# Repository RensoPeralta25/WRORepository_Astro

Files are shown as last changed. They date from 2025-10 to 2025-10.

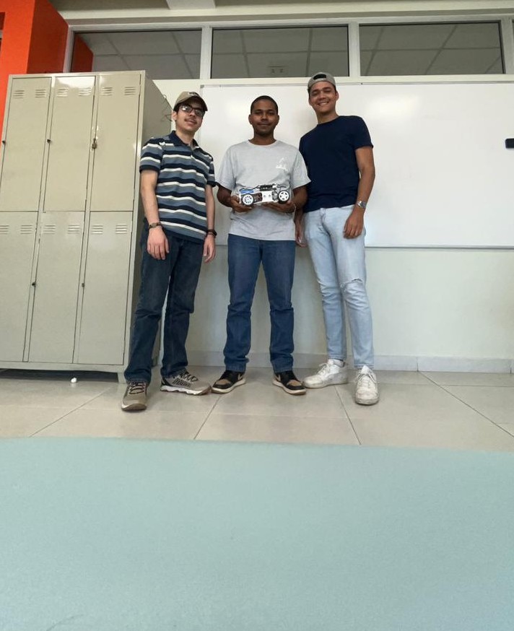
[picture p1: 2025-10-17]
t-photos/team photo.jpg

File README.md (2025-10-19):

# WRO Repository TEAM Astro
## Team Information

<p align="center">
  
</p>

📜 Documenter: Renso Isael Peralta Ureña (Right)

🧑‍🔧 Programmer: José Miguel Comprés Arias (Left)

🧑‍🔧 Mechanic: Yoel Samuel Castillo Castillo (Front)

team photo

PUCMM, Dominican Republic 

## Content Organization

This repository contains the complete documentation and resources for our autonomous vehicle designed for the WRO 2025 Future Engineers category from ASTRO team.

## Table of Contents

- [Introduction](#introduction)
- [Project Overview](#project-overview)
- [Models](#models)
  - [Main Components](#main-components)
  - [First Prototype Design](#first-prototype-design)
  - [Second Prototype Design](#second-prototype-design)
- [Sources (src)](#sources-src)
  - [Arduino Code](#what-does-this-code-do)
  - [Button Launcher](#code-bottompy)
  - [Autonomous Navigation](#code-openchallengepy)
- [Schemes](#schemes)
- [Vehicle Photos](#v-photos)

### Repository Structure

* **`t-photos`** - Contains the photo of the team:
  * Official team photo with all members

* **`v-photos`** - Contains 6 photos of the vehicle showcasing:
  * Front view
  * Back view
  * Left side view
  * Right side view
  * Top view
  * Bottom view

* **`videos`** - Contains `video.md` file with links to driving demonstration videos including:
  * Tests carried out

* **`schemes`** - Contains electromechanical schematic diagrams (JPEG/PNG/PDF form``at) illustrating:
  * IMU (MPU-9250) I2C Connection Diagram
  * Complete System Wiring Diagram
  * Dual Ultrasonic Sensors Configuration
  * Power Distribution

* **`src`** - Contains the control software source code:
  * Open Challenge 
  * projecthub.arduino.cc
  * bottom.py

* **`models`** - Contains 3D models and design files:
  * Files for 3D-printed parts.
  * First prototype design files.
  * Second prototype design files (optimized version).

## Introduction
This project presents our autonomous vehicle designed for the 2025 World Robot Olympiad (WRO) competition in the Future Engineers category. The robot is fully autonomous, capable of navigating a closed course, detecting and avoiding objects.

AUTONOMOUS NAVIGATION ROBOT

## Project Overview
This repository contains all the technical documentation, code, and design files for our autonomous navigation robot developed for the WRO Future Engineers. Our project focuses on creating a practical and efficient self-driving vehicle capable of navigating complex environments using sensor fusion and intelligent decision-making algorithms.

## Models

### Main components
- **Main Controller**: Raspberry Pi 5 (high-level processing)


[Link to buy the raspberry pi 5](https://www.amazon.com/-/es/SC1112-Raspberry-Pi-5-8GB/dp/B0CK2FCG1K/ref=sr_1_3_mod_primary_new?sr=8-3)

- **Real-time Controller**: Arduino UNO R3


[Link to buy the arduino UNO R3](https://www.amazon.com/-/es/Arduino-Uno-R3-Microcontrolador-A000066/dp/B008GRTSV6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)

- **Interface Board**: Robot Hat v4


[Link to buy Robot Hat v4](https://www.amazon.com/-/es/SunFounder-expansi%C3%B3n-Raspberry-conductores-recargable/dp/B0CKTD7QJB)

- **Sensors**:
  - 2x Ultrasonic sensors HCSR04 (Bilateral coverage)
  
  

  [Link to buy ultrasonic sensors HCSR04](https://www.amazon.com/-/es/DIYables-ultras%C3%B3nico-HC-SR04-Arduino-Raspberry/dp/B0BDFLPZ2R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)

  - 1x Color sensor TCS 3200 (line detection)
  
  

  [Link to buy Color Sensor TCS 3200](https://www.amazon.com/-/es/Teyleten-TCS3200-TCS230-reconocimiento-Arduino/dp/B08HH8QYF8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)

  - 1x IMU MPU-9250 (orientation)
  
  

  [Link to buy IMU MPU-9250](https://www.amazon.com/-/es/giroscopio-magn%C3%A9tico-aceleraci%C3%B3n-acelerador-magnet%C3%B3metro/dp/B01I1J0Z7Y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)
 
  - 1x Raspberry Pi Camera (computer vision)
  
  

  [Link to buy Raspberry Pi Camera](https://www.amazon.com/-/es/Arducam-peque%C3%B1o-megapixeles-pixeles-Raspberry/dp/B012V1HEP4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)

- **Motors**: TT Motor x1
  
  

  [Link to buy TT Motor](https://www.amazon.com/-/es/Diann-unids-Motor-cambios-200RPM/dp/B0BR7S2TRY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)

- **Power Source**: Battery
  
  

  [Link to buy Battery](https://www.indiamart.com/proddetail/5v-li-ion-battery-22444168691.html)

## First Prototype Design



Our initial chassis design was conceived with a compact, enclosed structure that prioritized sensor integration and component protection. The first prototype incorporated the following design elements:

*Sensor Layout*:
The chassis featured mounting positions for four ultrasonic sensors strategically distributed to provide comprehensive obstacle detection coverage around the vehicle's perimeter.

*Camera Integration*:
A dedicated frontal mounting space was designed to house the Raspberry Pi Camera module, positioned to provide an optimal field of view for computer vision and object detection tasks.

*Internal Electronics Compartment*:
The original design included an enclosed internal cavity intended to house all electronic components, including the Raspberry Pi 5, Robot Hat v4, Arduino, sensors, and wiring. This approach aimed to protect the electronics from external interference and provide a clean, organized appearance.

*Motor Placement*:
A designated space was allocated for the DC motor; however, the initial design lacked detailed consideration for motor mounting mechanics, power transmission, and drivetrain integration.

*Critical Design Oversight*:
During the physical assembly phase, we encountered a significant spatial constraint that was not apparent in the CAD model. The combined height of the Raspberry Pi 5 board and the Robot Hat v4 interface board exceeded the available vertical clearance within the internal compartment. We had not physically measured these stacked components during the design phase, assuming the CAD dimensions would accommodate them.

*Consequence*: The electronics could not fit inside the chassis as originally planned.

*Immediate Solution*: We repositioned the Raspberry Pi 5 and Robot Hat v4 assembly on top of the chassis structure, securing them with standoffs and mounting brackets. While this modification solved the spatial issue and improved heat dissipation and accessibility, it exposed the electronics to potential impacts and increased the vehicle's center of gravity.

Motor Integration Challenge:
Similarly, the motor mounting system was insufficiently detailed in the first prototype. The lack of proper motor brackets, shaft alignment considerations, and drivetrain coupling mechanisms became evident during assembly.

Resolution: This oversight necessitated a complete chassis redesign to properly integrate the motor system, optimize weight distribution, and ensure reliable power transmission to the wheels.

This experience highlighted the critical importance of:

*Physical measurement and test-fitting of components before finalizing CAD designs
Accounting for tolerance stack-up and assembly clearances
Detailed planning of mechanical subsystems (motor mounts, drivetrain, wiring routes)
Iterative prototyping to validate design assumptions*

These challenges directly informed the development of our second prototype, which addressed all identified spatial and mechanical integration issues.

## Second Prototype Design

After evaluating the limitations of our first prototype, we decided to completely redesign the chassis to optimize sensor positioning and improve overall functionality. Building on lessons learned, we planned to incorporate five ultrasonic sensors for enhanced environmental awareness.

Ultrasonic Sensor Holder Design

chasis largo

We designed a dedicated ultrasonic sensor holder to accommodate the five sensors we intended to use: two positioned at the front for forward obstacle detection, one at the rear for reverse awareness, and two mounted mid-chassis for lateral coverage. While this configuration seemed optimal in theory, practical testing revealed a critical flaw—the two front-mounted sensors created physical interference with the front wheel assembly during steering maneuvers, necessitating their removal from the chassis.



Front Wheel Support Structure

soporte rueda

Unlike the first design, the second prototype featured an improved front wheel support system. This component served a dual purpose: securely mounting the wheel assembly while providing a stable connection point to the vehicle's outer cover. The redesigned support improved structural rigidity and simplified the assembly process.

segundo soporte ruedas

Second Prototype Assembly Views



🔧 Challenges and Solutions During Final Design

During the development and assembly of our autonomous vehicle, we encountered several technical challenges that required creative solutions and design modifications. These challenges taught us valuable lessons about iterative design and practical engineering problem-solving.



Dimensional Compliance: Reducing Vehicle Length

Critical Constraint: Competition regulations required vehicles to not exceed specific dimensional limits. Our second prototype measured 11.8 inches in length, exceeding the maximum allowed dimension by one full inch.



Problem: The chassis design, while functionally sound, was too long to comply with competition rules. The extended length was primarily due to:

The frontal sensor mounting structure extending beyond necessary limits
The battery holder positioned too far forward
Overall chassis design that prioritized component spacing over compactness

Solution - Comprehensive Chassis Modification:
We implemented a series of strategic modifications to reduce the vehicle's footprint:

Front Section Reduction: We cut and removed approximately one inch from the front portion of the chassis, eliminating excess material while maintaining structural integrity for the camera mount and essential frontal components.

Color Sensor Relocation: Instead of mounting the TCS 3200 color sensor externally on the front surface, we created a custom opening on the underside (bottom) of the chassis. This modification allowed us to recess the sensor into the chassis body, positioning it closer to the ground for optimal line detection while recovering valuable frontal space.

Battery Holder Repositioning: We recessed the battery mounting bracket deeper into the chassis cavity, moving it further back from the front edge. This change not only reduced overall length but also improved weight distribution by centering the battery mass.



Ultrasonic Sensor Reduction: To accommodate the shortened chassis and address other constraints (detailed below), we removed three ultrasonic sensors from the design, further simplifying the frontal structure.

Result: These combined modifications successfully reduced the vehicle length from 11.8 inches to 10.8 inches, achieving full compliance with competition regulations while maintaining all essential functionality.

Arduino Pin Limitations and Sensor Reduction

Problem: Our initial plan to use five ultrasonic sensors, combined with the color sensor, IMU, camera interface, servo motor, and DC motor driver, exceeded the available GPIO pins on the Arduino UNO R3. Each ultrasonic sensor requires two digital pins (trigger and echo), meaning five sensors would consume 10 pins alone, leaving insufficient pins for other critical components.

Solution: We strategically reduced the ultrasonic sensor count from five to two, retaining only the most essential sensors for navigation:

One front-facing sensor for primary obstacle detection
One side-mounted sensor for wall-following and lateral awareness



This reduction freed up six digital pins (3 sensors × 2 pins each), allowing all remaining components to be properly connected without requiring a larger microcontroller.
Ultrasonic Sensor Interface Selection: Raspberry Pi vs. Arduino
Problem: During initial testing, we attempted to interface the ultrasonic sensors directly with the Raspberry Pi 5 GPIO pins. However, we encountered persistent issues with unreliable distance readings and inconsistent sensor response times. The problem stemmed from the Raspberry Pi's non-real-time operating system (Linux), which cannot guarantee precise microsecond-level timing required for accurate ultrasonic echo pulse measurement.
Solution: We decided to connect the ultrasonic sensors to the Arduino UNO R3 instead of the Raspberry Pi. The Arduino's real-time microcontroller architecture provides deterministic timing, ensuring accurate pulse duration measurements. The Arduino reads the sensor data and transmits processed distance values to the Raspberry Pi via serial communication (UART) through the Robot Hat v4 interface.
Technical Justification:

Arduino UNO R3: Real-time operation with precise microsecond timing for reliable ultrasonic measurements
Raspberry Pi 5: Handles higher-level processing (computer vision, navigation logic, decision-making) without timing-critical sensor interfacing

This division of responsibilities between the two processors optimized system reliability and performance.
Color Sensor Integration
One of the first challenges we faced was fitting the color sensor into its designated mounting space. The original CAD design did not account for the actual physical dimensions and connector orientation of the TCS 3200 color sensor module.
Problem: The color sensor module, including its I2C connector pins, exceeded the allocated space in the front sensor mount structure. The rigid PCB design prevented us from repositioning it without structural modifications.
Solution: We used a soldering iron to carefully create a custom opening in the bottom of the plastic chassis. This allowed us to recess the sensor body while keeping the optical window at the optimal height and angle for line detection. The modification maintained the sensor's downward-facing orientation (approximately 30-45° angle) necessary for accurate color detection of the track surface while minimizing ambient light interference.
Result: The color sensor was successfully integrated and provided reliable line detection throughout testing while contributing to the overall length reduction of the chassis.
Rear Wheel Support Structure Failure
Problem: The 3D-printed rear wheel support arms, designed to hold rubber tires in place, experienced structural failure during initial testing. The stress concentration points where the tires connected to the motor shafts caused the plastic supports to crack and eventually break. This was likely due to:

Insufficient wall thickness in the 3D-printed part
Vibrations from the DC motors during operation
Lateral forces during turning maneuvers

Solution: Unable to quickly redesign and reprint the support structure, we implemented an emergency repair using a soldering iron technique:

We carefully heated the soldering iron to a temperature suitable for melting PLA/ABS plastic
We repositioned the broken rubber tire holders against the motor mounting arms
We used the soldering iron tip to "weld" the plastic pieces together, creating a reinforced joint
We added additional plastic material where needed to strengthen critical stress points

Result: This field repair successfully restored structural integrity and proved durable enough for the remainder of our testing and competition preparation. However, this experience highlighted the importance of stress testing 3D-printed components and designing with appropriate safety margins for dynamic loads.
Microcontroller Selection Optimization
Our electronic architecture underwent a significant simplification during the final assembly phase.
Original Plan: Arduino Mega 2560

Reason for selection: The Mega provides 54 digital I/O pins and 16 analog inputs, which we initially believed necessary to accommodate multiple ultrasonic sensors, the color sensor (I2C), the IMU (I2C), servo motors (PWM pins), and the DC motor driver.

Modified Implementation: Arduino UNO R3

Reason for change: After reducing the ultrasonic sensor count to two, the total pin requirement decreased significantly:

2 ultrasonic sensors: 4 digital pins (2 trigger + 2 echo)
Color sensor: I2C bus (SDA/SCL) - 2 pins
IMU: I2C bus (shared) - 0 additional pins
Servo motor (steering): 1 PWM pin
DC motor driver: 2-4 digital pins
Total: approximately 9-11 pins

The Arduino UNO R3 provides 14 digital I/O pins and 6 analog inputs, which is more than sufficient for our reduced configuration. This change offered several advantages:

Reduced physical footprint: The Uno is smaller and lighter than the Mega
Improved space utilization: Easier to fit within the compact chassis
Cost optimization: Lower component cost without sacrificing functionality
Simplified wiring: Fewer unused pins reduced wiring complexity
Real-time sensor reliability: Better ultrasonic sensor performance compared to Raspberry Pi GPIO

Power Distribution Solution
Managing multiple 5V power connections for sensors and modules with limited power pins on the Arduino.
Solution: We implemented a breadboard-based power distribution system:

Positive rail (5V): Connected to Arduino's 5V output pin
Ground rail (0V/GND): Connected to Arduino's GND pin
Connected devices: All sensors requiring 5V power (ultrasonic sensors, color sensor) were connected to the breadboard rails

Advantages:

Organized and accessible power distribution
Easy troubleshooting and component replacement
Reduced stress on Arduino's voltage regulator by distributing current load
Clean cable management

## Sources (src)

File: projecthub.arduino.cc

## What does this code do?

This code controls an Arduino robot that can:
- **Detect distances** to the left and right using ultrasonic sensors
- **Identify colors** using a TCS3200/230 sensor
- **Rotate** using a servo motor
- **Communicate** with a computer via serial port

## Hardware Connections

### Left Ultrasonic Sensor:
- `TRIG` → Pin 7
- `ECHO` → Pin 6
- `VCC` → 5V
- `GND` → GND

### Right Ultrasonic Sensor:
- `TRIG` → Pin 5
- `ECHO` → Pin 4
- `VCC` → 5V
- `GND` → GND

### TCS3200 Color Sensor:
- `S0` → Pin 8
- `S1` → Pin 9
- `S2` → Pin 10
- `S3` → Pin 11
- `OUT` → Pin 12
- `VCC` → 5V
- `GND` → GND

### Servo Motor:
- Signal Wire → Pin 3
- Red Wire → 5V
- Brown/Black Wire → GND

## 📚 Required Libraries

Before uploading the code, install these Libraries:

```cpp
#include <Servo.h> // To control the servo
#include <SR04.h> // For ultrasonic sensors
```

**Installation:** In the Arduino IDE, go to `Tools > Manage Libraries` and search for these libraries.

## Step-by-Step Code Explanation

### 1. Pin Definitions

```cpp
// ULTRASONIC PINS
#define TRIG_PIN_L 7 // Left sensor trigger pin
#define ECHO_PIN_L 6 // Left sensor echo pin
#define TRIG_PIN_R 5 // Right sensor trigger pin
#define ECHO_PIN_R 4 // Right sensor echo pin

// COLOR SENSOR PINS
#define s0 8 // Frequency setting
#define s1 9 // Frequency setting
#define s2 10 // Color filter selection
#define s3 11 // Color filter selection
#define out 12 // Frequency output

// SERVO PIN
#define SERVO_PIN 3 // Servo control pin
```

### 2. Variables globals

```cpp
int data = 0; // Stores the color frequency
int degs; // Degrees for the servo
long distance_usl; // Left sensor distance
long distance_usr; // Right sensor distance
```

### 3. Object Creation

```cpp
SR04 ul = SR04(ECHO_PIN_L, TRIG_PIN_L); // Left ultrasonic sensor
SR04 ur = SR04(ECHO_PIN_R, TRIG_PIN_R); // Right ultrasonic sensor
Servo servo; // Servo object
```

### 4. Initial Setup

```cpp
void setup() {
Serial.begin(9600); // Start serial communication

// Configure color sensor pins
pinMode(s0, OUTPUT);
pinMode(s1, OUTPUT);
pinMode(s2,OUTPUT);
pinMode(s3,OUTPUT);
pinMode(out,INPUT);

// Sets frequency to 100% (maximum precision)
digitalWrite(s0,HIGH);
digitalWrite(s1,HIGH);

// Starts servo in center position (70°)
servo.attach(SERVO_PIN);
servo.write(70);

delay(2000); // Waits 2 seconds to stabilize
}
```

### 5. Main Loop

The code performs the following operations continuously:

#### a) Servo control via serial
```cpp
if (stringComplete) {
inputString.trim(); // Clears spaces
degs = inputString.toInt(); // Converts text to numbers
servo.write(degs); // Move the servo
inputString = "";
stringComplete = false;
}
```

**Servo limits:**
- Right: 30°
- Left: 130°
- Center: ~70-80°

#### b) Reading ultrasonic sensors
```cpp
distance_usl = ul.Distance(); // Left distance in cm
distance_usr = ur.Distance(); // Right distance in cm
```

#### c) Reading the color sensor

The sensor detects the RGB components of the reflected light:

```cpp
// Detect RED
digitalWrite(s2, LOW);
digitalWrite(s3, LOW);
int r = pulseIn(out, LOW);

// Detect GREEN
digitalWrite(s2, LOW);
digitalWrite(s3, HIGH);
int g = pulseIn(out, LOW);

// Detect BLUE
digitalWrite(s2, HIGH);
digitalWrite(s3, HIGH);
int b = pulseIn(out, LOW);
```

**How does it work?**
- S2/S3 combinations select which color to detect
- `pulseIn` measures the pulse time (shorter time = greater color intensity)

#### d) Sending data
```cpp
Serial.println(String(distance_usl) + "|" + String(distance_usr) + "|" +
String(r) + "|" + String(g) + "|" + String(b));
```

Output format: `distance_left|distance_right|red|green|blue`

### 6. Receiving serial commands

```cpp
void serialEvent() {
while (Serial.available()) {
char inChar = (char)Serial.read();
if (inChar == '\n') {
stringComplete = true; // Mark the command complete
} else {
inputString += inChar; // Construct the command
}
}
}
```

This function is executed automatically when data arrives via serial.

## Code: bottom.py

This Python script creates a simple button-controlled system that:

Monitors a button for press events
Controls an LED to indicate button state
Launches another Python script when the button is pressed
Prevents accidental multiple triggers with debouncing

This is perfect for robots or projects where you need a physical button to start a specific program or routine.
Required Libraries
This project uses the robot_hat library, which is typically included with SunFounder robot kits:
bash# If not already installed:
pip3 install robot-hat
```

## 🔌 Hardware Connections

### Button Connection:
- One side → GPIO25 (labeled as "SW" on some boards)
- Other side → GND
- Internal pull-up resistor enabled (no external resistor needed)

### LED Connection:
- LED anode (long leg) → GPIO26 through 220Ω resistor
- LED cathode (short leg) → GND

```
              +         -
Code Explanation - Line by Line
1. Import Required Libraries
pythonfrom robot_hat import Pin
import time
import os

robot_hat: Provides easy GPIO control for Raspberry Pi
time: For delays and preventing button bounce
os: To execute system commands (run other scripts)

2. Hardware Setup
pythonbutton = Pin("SW", Pin.IN, Pin.PULL_UP)   # Button USR (GPIO25)
led = Pin(26, Pin.OUT)                    # LED (GPIO26)
Button Configuration:

"SW": Special label for GPIO25 (user switch)
Pin.IN: Sets pin as input
Pin.PULL_UP: Enables internal pull-up resistor

Button reads HIGH (1) when not pressed
Button reads LOW (0) when pressed

LED Configuration:

26: GPIO pin number
Pin.OUT: Sets pin as output

3. Define Script Path
python# Path to the file you want to execute
script_path = "/home/admin/Documents/pruebaAbierta1.py"
This is the full path to the Python script that will run when the button is pressed.
Important: Update this path to match your script location!
4. Main Control Loop
pythonwhile True:
    if button.value() == 1:  # Pressed
        led.on()
        os.system(f"python3 {script_path}")  # Execute the other script
        time.sleep(0.5)  # Avoid repetition due to bounce
    else:
        led.off()
    time.sleep(0.1)
Loop Behavior:

Button Check: button.value() returns:

1 when button is pressed (connected to ground)
0 when button is not pressed (pulled high)

When Button is Pressed:

LED turns ON
External script executes using os.system()
0.5 second delay prevents multiple triggers (debouncing)

When Button is Released:

LED turns OFF

Loop Delay:

0.1 second delay reduces CPU usage
Provides responsive button checking (~10 checks per second)

How to Use This Code
Step 1: Setup Your Hardware

Connect the button to GPIO25 and GND
Connect the LED to GPIO26 (with resistor) and GND
Power up your Raspberry Pi

Step 2: Prepare Your Scripts

Save this launcher script (e.g., as button_launcher.py)
Create or locate the script you want to launch
Update the script_path variable with the correct path

Step 3: Run the Launcher
bashpython3 button_launcher.py
Step 4: Test the System

Press the button → LED lights up and your script runs
Release the button → LED turns off
The launcher continues running, ready for the next press

Use Cases
This button launcher is perfect for:

Robot startup sequences - Press to begin autonomous navigation
Data collection triggers - Start sensor logging on demand
Mode switching - Toggle between different robot behaviors
Emergency stops - Launch shutdown or safe mode scripts
Demo activation - Start presentation routines

## Code: openChallenge.py

This Python script creates an autonomous robot that:
- **Navigates using ultrasonic sensors** (left and right distance detection)
- **Adjusts steering automatically** based on sensor readings
- **Captures video feed** from a Raspberry Pi camera
- **Detects colored lines** for navigation markers (using RGB sensor)
- **Communicates with Arduino** via serial for sensor data and servo control

The robot uses a wall-following algorithm to navigate corridors or paths while avoiding obstacles.

### Software Requirements:
```bash
# Install required Python packages
pip3 install pyserial
pip3 install opencv-python
pip3 install picamera2
# Astro library (specific to robot kit)
```

## System Architecture

```

┌─────────────┐     Serial      ┌─────────────┐
│  Raspberry  │◄──────────────► │   Arduino   │
│     Pi      │    /dev/ttyACM0 │             │
└──────┬──────┘                 └──────┬──────┘
       │                                │
   ┌───┴───┐                     ┌─────┴─────┐
   │  HAT  │                     │  Sensors  │
   └───┬───┘                     │  & Servo  │
       │                         └───────────┘
   ┌───┴───┐
   │ Motor │
   └───────┘

```

## Key Parameters and Constants

```python
SERIAL_PORT = "/dev/ttyACM0"  # Arduino serial connection
BAUD_RATE   = 9600            # Serial communication speed

DISCR_DIST  = 3               # Distance threshold (unused in current version)
REDIR_ANGLE = 40              # Redirection angle for turns
CENTER = 70                   # Servo center position (degrees)
MAX_ANGLE = 40                # Maximum steering angle from center
```

### Servo Limits:
- **Minimum angle**: CENTER - MAX_ANGLE = 30°
- **Maximum angle**: CENTER + MAX_ANGLE = 110°
- **Center/Straight**: 70°

##  Code Explanation - Section by Section

### 1. Imports and Setup

```python
from astro import Astro      # Robot control library
import serial                # Arduino communication
import time                  # Delays and timing
import cv2                   # Image processing
from picamera2 import Picamera2  # Camera interface
```

### 2. Camera Initialization

```python
picam2 = Picamera2()

# Configure camera resolution
config = picam2.create_preview_configuration({"size": (640, 480)})
picam2.configure(config)

picam2.start()
time.sleep(0.2)  # Allow camera to stabilize
```

The camera runs at 640x480 resolution for a balance between quality and performance.

### 3. Helper Functions

#### Constrain Function
```python
def constrain(x, mn, mx):
    return max(mn, min(mx, x))
```
Limits a value between minimum and maximum bounds (used for servo angles).

#### Serial Communication
```python
def sensor_comm(command):
    ser.write((command + "\n").encode('utf-8'))
```
Sends commands to Arduino (primarily servo angle values).

### 4. Data Reading Functions

The code includes three versions of the data reading function, with `leer_datos3` being the most robust:

```python
def leer_datos3(timeout_seconds=1.0):
    start = time.time()
    
    while True:
        linea = ser.readline().decode(errors="ignore").strip()
        
        # Timeout check
        if not linea:
            if time.time() - start > timeout_seconds:
                raise ValueError("Timeout: no data received")
            continue
        
        # Format validation
        if "|" not in linea:
            if time.time() - start > timeout_seconds:
                raise ValueError(f"Malformed line: {linea!r}")
            continue
        
        # Parse data
        partes = linea.split("|")
        
        # Pad missing values with zeros
        while len(partes) < 5:
            partes.append("0")
        
        # Extract values
        usl_str, usr_str, r_str, g_str, b_str = partes[:5]
        
        try:
            usl = float(usl_str)  # Left ultrasonic
            usr = float(usr_str)  # Right ultrasonic
            r = float(r_str)      # Red component
            g = float(g_str)      # Green component
            b = float(b_str)      # Blue component
            return usl, usr, r, g, b
        except ValueError:
            if time.time() - start > timeout_seconds:
                raise
            continue
```

**Data Format**: `left_distance|right_distance|red|green|blue`

### 5. Main Navigation Loop

```python
# Initialize robot
bot = Astro()
line_count = 0

bot.stop()
time.sleep(5)  # Wait before starting

# Get initial sensor sum
left_dist, right_dist, r, g, b = leer_datos3()
Sum_Initial = left_dist + right_dist

while True:
    # Move forward
    bot.forward(90)  # Speed: 90
    
    # Read sensors
    left_dist, right_dist, r, g, b = leer_datos3()
    
    # Capture and display camera image
    img = picam2.capture_array()
    img_bgr = cv2.cvtColor(img, cv2.COLOR_RGB2BGR)
    cv2.imshow("CSI Camera (Picamera2 -> OpenCV)", img_bgr)
    
    # Calculate current sum
    Sum_Temp = left_dist + right_dist
    
    # Navigation algorithm
    if(Sum_Temp - 10 < Sum_Initial):
        # Walls closing in - adjust based on difference
        angle = CENTER + float(left_dist - right_dist) * (float(MAX_ANGLE) / 30)
        sensor_comm(str(constrain(angle, CENTER - MAX_ANGLE, CENTER + MAX_ANGLE)))
        
    elif(Sum_Temp - 10 > Sum_Initial):
        # Walls opening up - adjust based on sum
        angle = CENTER + float(left_dist + right_dist) * (float(MAX_ANGLE) / 30)
        sensor_comm(str(constrain(angle, CENTER - MAX_ANGLE, CENTER + MAX_ANGLE)))
        
    else:
        # Maintain center
        sensor_comm("70")
```

### 6. Navigation Algorithm Explained

The robot uses a **corridor-following algorithm**:

1. **Initial Calibration**: Records the sum of left and right distances at start
2. **Continuous Monitoring**: Compares current sum with initial sum
3. **Steering Decisions**:
   - **Walls closing in** (Sum_Temp < Sum_Initial - 10):
     - Steers based on the difference between sensors
     - Moves away from the closer wall
   - **Walls opening up** (Sum_Temp > Sum_Initial + 10):
     - Uses the sum of distances for steering
     - Helps navigate open areas
   - **Normal corridor**: Maintains center position

### 7. Alternative Navigation Code (Commented Out)

The code includes an alternative navigation method:

```python
# Smooth out noisy readings
real_l = left_dist
if (abs(last_l - left_dist) > 10):
    real_l = last_l  # Use last value if change too large

# Different steering sensitivity based on distance difference
if abs(left_dist - right_dist < 40):
    # Normal steering
    angle = CENTER + float(real_l - real_r) * (float(MAX_ANGLE) / 20)
else:
    # More aggressive steering for larger differences
    angle = CENTER + float(real_l - real_r) * (float(50) / 20)

# Line detection for counting laps/sections
if min(r, min(g, b)) == r and r < min(g, b):
    line_count += 1  # Red line detected
```

### 8. Error Handling

```python
try:
    # Main code
except serial.SerialException as e:
    print(f"ERROR opening port: {e}")
except KeyboardInterrupt:
    print("\nReading stopped by user.")
finally:
    # Cleanup
    if 'ser' in locals() and ser.is_open:
        ser.close()
    picam2.stop()
    cv2.destroyAllWindows()
```

## How to Use This Code

### Step 1: Hardware Setup
1. Connect Arduino to Raspberry Pi via USB
2. Upload the Arduino sensor code (from previous tutorial)
3. Mount ultrasonic sensors pointing left and right
4. Connect camera to CSI port
5. Ensure robot wheels and servo are properly connected

### Step 2: Software Configuration
1. Find Arduino port:
   ```bash
   ls /dev/tty*  # Look for /dev/ttyACM0 or /dev/ttyUSB0
   ```
2. Update `SERIAL_PORT` if different
3. Install required libraries

### Step 3: Run the Robot
```bash
python3 autonomous_robot.py
```

### Step 4: Monitor Operation
- Camera feed window shows real-time view
- Terminal displays sensor readings
- Press `Ctrl+C` to stop safely

## Understanding the Output

### Terminal Output:
```
RAW: 15|20|150|200|180
Distancia izquierda: 15.0
Distancia derecha: 20.0
Sumatoria Inicial: 35.0
Sumatoria: 35.0
```

- **RAW**: Raw serial data from Arduino
- **Distance values**: In centimeters
- **Sum values**: Used for navigation decisions

## 🔧 Tuning and Optimization

### 1. Steering Sensitivity
```python
# Current formula: MAX_ANGLE / 30
# Increase divisor for less sensitive steering
angle = CENTER + float(left_dist - right_dist) * (float(MAX_ANGLE) / 30)

# More sensitive (faster reactions)
angle = CENTER + float(left_dist - right_dist) * (float(MAX_ANGLE) / 20)

# Less sensitive (smoother movement)
angle = CENTER + float(left_dist - right_dist) * (float(MAX_ANGLE) / 40)
```

### 2. Speed Control
```python
# Current: constant speed
bot.forward(90)

# Dynamic speed based on obstacles
if min(left_dist, right_dist) < 15:
    bot.forward(60)  # Slow down near walls
else:
    bot.forward(90)  # Normal speed
```

### 3. Wall Detection Threshold
```python
# Current: 10cm buffer
if(Sum_Temp - 10 < Sum_Initial):

# More sensitive to changes
if(Sum_Temp - 5 < Sum_Initial):

# Less sensitive (for wider corridors)
if(Sum_Temp - 15 < Sum_Initial):
```

## Advanced Features

### Add Obstacle Avoidance
```python
# Emergency stop for close obstacles
if min(left_dist, right_dist) < 5:
    bot.stop()
    time.sleep(0.5)
    bot.backward(70)
    time.sleep(1)
```

### Implement PID Control
```python
# Simple proportional control upgrade
error = left_dist - right_dist
integral += error * dt
derivative = (error - last_error) / dt

# PID formula
steering = Kp * error + Ki * integral + Kd * derivative
angle = CENTER + constrain(steering, -MAX_ANGLE, MAX_ANGLE)
```

### Add Path Memory
```python
path_history = []
position_estimate = {"x": 0, "y": 0, "heading": 0}

# Log movements
path_history.append({
    "time": time.time(),
    "left": left_dist,
    "right": right_dist,
    "steering": angle
})
```

## Troubleshooting

### Serial Communication Issues:
- **"No data received"**: Check Arduino is sending data
- **"Malformed line"**: Verify Arduino data format
- **Permission denied**: Add user to dialout group
  ```bash
  sudo usermod -a -G dialout $USER
  ```

### Camera Issues:
- **Black screen**: Enable camera in `raspi-config`
- **Import error**: Install picamera2 dependencies
- **Slow performance**: Reduce resolution

### Navigation Problems:
- **Hitting walls**: Increase MAX_ANGLE or sensitivity
- **Zigzag movement**: Decrease sensitivity or add smoothing
- **Not turning**: Check servo connections and limits

## Performance Optimization

### 1. Reduce Serial Latency
```python
# Add to setup
ser.set_low_latency_mode(True)
```

### 2. Optimize Image Processing
```python
# Skip frames for display
frame_count = 0
if frame_count % 5 == 0:  # Show every 5th frame
    cv2.imshow("Camera", img_bgr)
frame_count += 1
```

### 3. Multi-threading
```python
import threading

def camera_thread():
    while running:
        img = picam2.capture_array()
        # Process image
        
def sensor_thread():
    while running:
        data = leer_datos3()
        # Process sensors
```
## Schemes

Overview
These schematics show the complete wiring connections for an autonomous robot using Arduino UNO R3 as the main microcontroller, featuring multiple sensors for navigation and environmental awareness.

IMU (MPU-9250) I2C Connection Diagram



Components:

IMU Digital Combo Board 6DOF (MPU-9250)
Arduino UNO (Rev3)

Connection Details:

  Power Connections:

    3.3V (Red wire) → Arduino 3.3V pin
    GND (Green wire) → Arduino GND pin

  I2C Communication:

    SDA (Blue wire) → Arduino A4/SDA pin
    SCL (Green wire) → Arduino A5/SCL pin

Interrupt Pins (Not connected):

INT0 and INT1 pins are available but not utilized

Important Note: Although the IMU (MPU-9250) is physically connected and shown in the schematic, it is currently not being used in the code implementation due to time constraints. The hardware is ready for future integration when needed.

Complete System Wiring Diagram
This diagram shows the I2C connection between Arduino UNO R3 and the IMU module using the same color coding as diagrama 1.



Image 3: Arduino with Color Sensor (TCS3200)



Components:

Arduino UNO R3
TCS3200 Color Sensor Module

Physical Setup:

The color sensor is connected via jumper wires
Power is supplied through the Arduino's 5V and GND pins
Data pins are connected to digital I/O pins for color frequency reading

Dual Ultrasonic Sensors Configuration



Components:

Arduino UNO
2x HC-SR04 Ultrasonic Sensors
Breadboard (for power distribution)

Wiring Configuration:

Upper Ultrasonic Sensor (Left side):

VCC → 5V power rail (Red wire)
Trig → Digital Pin 7
Echo → Digital Pin 6
GND → Ground rail (Black wire)

Lower Ultrasonic Sensor (Right side):

VCC → 5V power rail (Red wire)
Trig → Digital Pin 5
Echo → Digital Pin 4
GND → Ground rail (Black wire)

Power Distribution:

The breadboard is used to distribute 5V and GND from Arduino to both sensors
This eliminates the need for multiple connections to Arduino's limited power pins

Additional Resources
Note: There is an additional file in the schemes folder called "Ultrasonic schematics" that shows the ultrasonic sensor connection diagram in a different format. This provides an alternative view of the same connections for better clarity.
System Integration Summary

Microcontroller: Arduino UNO R3 serves as the main processing unit

Sensors:
2x HC-SR04 Ultrasonic sensors (active and functioning)
1x TCS3200 Color sensor (active and functioning)
1x MPU-9250 IMU (connected but not implemented in software)

### Communication:

I2C bus for IMU (when implemented)
Digital I/O for ultrasonic sensors
Serial communication with Raspberry Pi via USB

### Power Management

All sensors operate at 5V except the IMU which requires 3.3V
Breadboard used for clean power distribution
Arduino provides regulated power to all components

This modular design allows for easy troubleshooting and future expansion of the sensor array.

## v-photos

### Front

front1

### Back

back1

### Bottom

bottom1

### Left
left1

### Right
right1

### Top
top1

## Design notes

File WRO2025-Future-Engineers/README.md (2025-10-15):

# WRO Repository TEAM Astro
## Introduction
This project presents our autonomous vehicle designed for the 2025 World Robot Olympiad (WRO) competition in the Future Engineers category. The robot is fully autonomous, capable of navigating a closed course, detecting and avoiding objects, and parking itself at the end of the course. 

What makes our design unique:

Our vehicle stands out for its redundant and robust sensor architecture: it integrates four strategically positioned ultrasonic sensors that provide full 360° perimeter detection, a color sensor for precise object identification, and an IMU (Inertial Measurement Unit) that allows the robot to maintain orientation and stability in real time.

The brain of the system is a state-of-the-art Raspberry Pi 5 working in conjunction with an Arduino Mega via the Robot Hat v4, creating a dual architecture that separates high-level processing (vision and decision-making) from real-time control (motors and sensors). This hybrid configuration guarantees ultra-fast responses and system stability.

Visually, the robot features a futuristic, technological design in white, reflecting innovation and modernity. The precision servo steering system ensures smooth and accurate maneuvers, while data fusion from multiple sensors enables reliable autonomous navigation even in challenging track conditions.
## ⚙️ Vehicle Design
- Drive system (e.g., differential rear-wheel)
- Motors (type and quantity) and power source (battery type and specs)
- Sensors used (line, distance, vision) and their location
- Brief summary of CAD and physical layout

### 🚀 First Prototype Design



Our first prototype was designed with a minimalist yet strategic approach to sensor integration and mechanical structure. The initial concept called for five ultrasonic sensors strategically distributed around the chassis to provide full 360-degree obstacle detection coverage: a front-facing center sensor for primary detection, two front-facing sensors angled at 45° (left and right) to cover side blind spots, and two side sensors at 90° for wall following and narrow-space detection. Additionally, a color sensor was integrated into a protruding rectangular structure on the front of the robot, specifically designed to position the sensor at an optimal height with a downward tilt angle to allow for accurate detection of the black circuit line, while minimizing ambient light interference thanks to its wraparound design. For advanced navigation and obstacle recognition, a camera was mounted on the top center of the chassis, enabling visual processing to identify and classify obstacles using computer vision algorithms. Finally, an IMU (Inertial Measurement Unit) was positioned on top of the robot, directly above the center of gravity, to provide precise orientation data (yaw, pitch, and roll angles) and stabilization during navigation, crucial for maintaining straight trajectories and executing turns with angular precision. The mechanical structure was complemented by front arms specifically designed for mounting the front wheels, providing an independent steering system that improves maneuverability and allows for precise turning radius adjustments. The rectangular configuration of the front color sensor mount not only fulfills its sensory function but also acts as a structural element that reinforces the front of the chassis and provides protection against minor impacts.

### 🚀 Second Prototype Design

After having thought about this sketch, for reasons of optimizing the position of sensors, we decided to completely change the design of our autonomous robot. As mentioned before, we wanted to have 6 ultrasonics, to help us have more vision. We took this into account for the next version of the design, and also at first we did not think about the location of the engine, this was optimized.





## 🧠 Software Architecture
- Overview of your control strategy
- Code modules (e.g., `line_tracking.py`, `sign_detection.py`)
- Communication or data flow between modules
- Programming language(s) and runtime platform (e.g., Raspberry Pi, Arduino)
## 🔧 Build Instructions
- List of all components used (with part numbers or links if possible)
- Step-by-step physical assembly instructions
- CAD file references or screenshots
## 💾 Code Deployment
- How to set up the environment
- How to install dependencies (requirements.txt)
- How to upload/execute code on your platform
- Any hardware-specific notes or configurations
## 🎥 Test and Evaluation Videos
- Add public links to at least 30-second videos for each required task:
  - Line Following
  - Traffic Sign Detection
  - Obstacle Avoidance
  - Autonomous Parking
- Include a brief description of each video
## 📁 Repository Structure
```text
📂 WRO2025-Future-Engineers/
├── README.md                    ← Main documentation file (min. 5000 characters, in English)
├── 📂 code/                     ← Complete source code (Python, C++, etc.)
│   ├── astro.py                 ← Main script controlling the robot
│   ├── modules/                ← Modular code (e.g., vision, movement, decisions)
│   │   ├── pruebaAbierta.py 
│   │   ├── sensors.ino
│   │   └── 
│   └── utils/                  ← Helper functions, constants, configuration
│       ├── 
│       └── 
├── 📂 hardware/
│   ├── photos/                 ← Photos of the robot (top, side, bottom views)
│   │   ├── 
│   │   ├── 
│   │   └── 
│   └── CAD/                    ← CAD files (STL, DXF, 3D models, PDF diagrams)
│       ├── PrototipoRobot.f3d
│       ├── 
│       └── 
├── 📂 docs/
│   ├──                        ← Scanned or digital engineering logbook
│   ├──                        ← Final technical design presentation
│   └──                        ← (Optional) Performance scoring tables
│       ├── 
│       └── 
├── 📂 videos/
│   ├──                        ← Text file with public video links (1 per challenge, min. 30 seconds each)
│   └──                        ← (Optional) Captures from each test or video
│       ├── 
│       └── 
├── 📄 LICENSE                  ← Open-source license (MIT or Creative Commons)
└── 📄 requirements.txt         ← List of Python or system dependencies

4. References and Resources

- WRO 2025 Official Rules (Future Engineers): https://wro-association.org/competition-categories/future-engineers/
- OpenCV Documentation: https://docs.opencv.org/
- Modern Robotics Book and Code (Kevin Lynch): https://www.modernrobotics.org/
- Python Official Documentation: https://docs.python.org/
- Creative Commons Licenses: https://creativecommons.org/licenses/
- MIT License Template: https://opensource.org/licenses/MIT
- GitHub Docs – Structuring a repository: https://docs.github.com/en/repositories
```
## 📜 License
This project is released under the MIT License (or other open license).
Feel free to reuse or adapt for educational purposes.
[Insert license text or reference to LICENSE file]

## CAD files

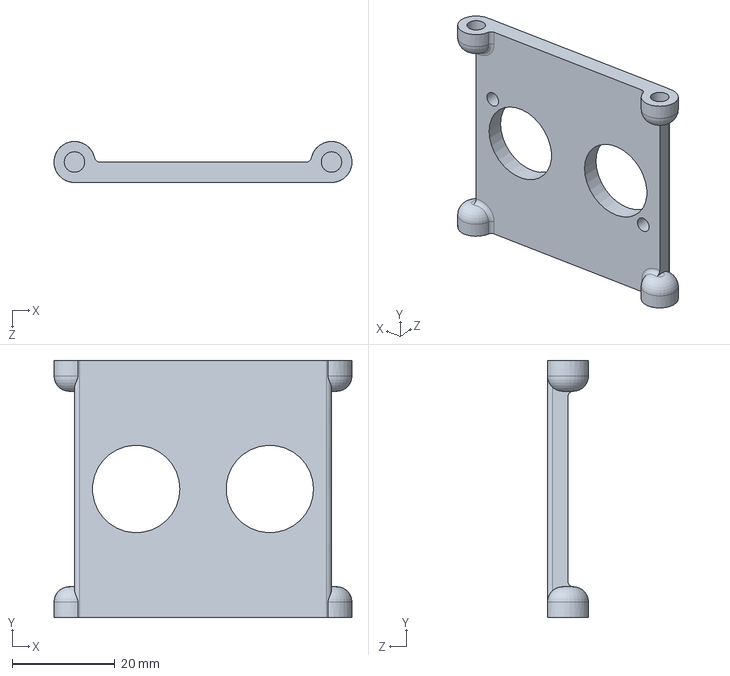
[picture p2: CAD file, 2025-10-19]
models/Ultrasonic holder.SLDPRT
58.0 x 50.0 x 8.00 mm

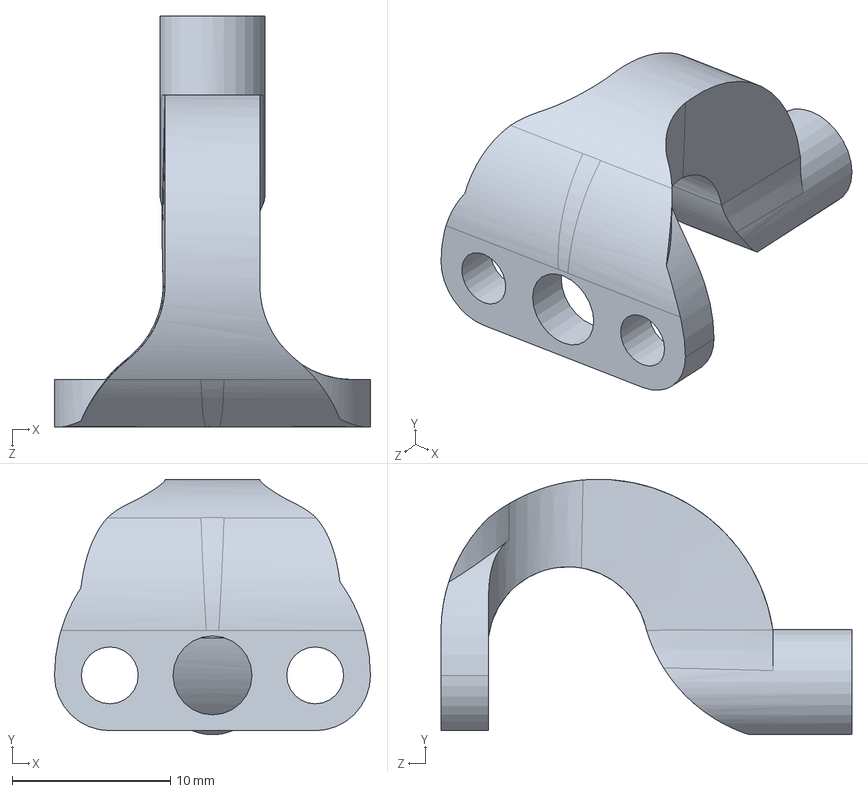
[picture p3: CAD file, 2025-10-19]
models/MCPerson.SLDPRT
20.0 x 16.2 x 26.0 mm

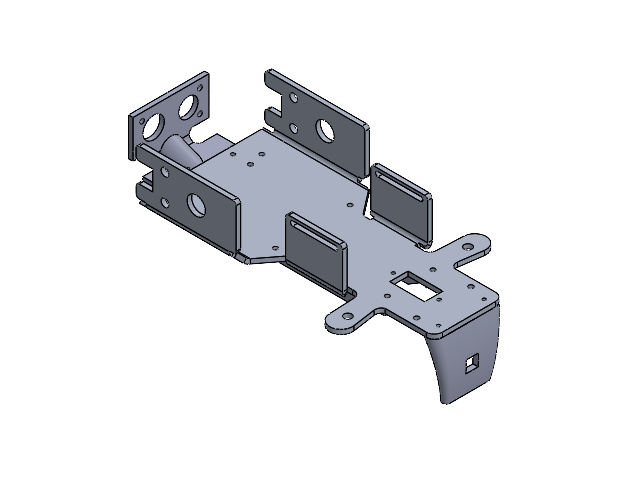
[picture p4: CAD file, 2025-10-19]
models/Ensamble.SLDASM
Chassis
refuerzo x 2
Soporte de camara
Soporte de sensor ultrasonic

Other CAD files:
models/PrototipoRobot.f3d

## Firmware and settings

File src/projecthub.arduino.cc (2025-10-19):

//#include <MPU9250.h>
#include <Servo.h>
#include <SR04.h>
 
//PINS FOR ULTRASONICS
#define TRIG_PIN_L  7
#define ECHO_PIN_L  6
#define TRIG_PIN_R  5
#define ECHO_PIN_R  4
 
//PINS FOR COLOR SENSOR
#define s0   8
#define s1   9
#define s2  10
#define s3  11
#define out 12
 
//PIN FOR DIR SERVO
#define SERVO_PIN 3
 
int data = 0; // Data variable used for reading the frequency of colors
int degs;

//Ultrasonic objects
SR04 ul = SR04(ECHO_PIN_L,TRIG_PIN_L);
SR04 ur = SR04(ECHO_PIN_R,TRIG_PIN_R);
 
//Servo object
Servo servo;
 
//MPU object
//MPU9250 mpu;
float yaw;
 
String inputString = "";      // To save what comes from serial
bool stringComplete = false;  // Flag to know if a string received from serial can be evaluated
 
long distance_usl;
long distance_usr;

void setup() {
  Serial.begin(9600);
  inputString.reserve(20);
 
  pinMode(s0,OUTPUT);    //pin modes
  pinMode(s1,OUTPUT);
  pinMode(s2,OUTPUT);
  pinMode(s3,OUTPUT);
  pinMode(out,INPUT);
  digitalWrite(s0,HIGH);  //Putting S0/S1 on HIGH/HIGH levels means the output frequency scalling is at 100%, which is recommended by https://projecthub.arduino.cc/SurtrTech/color-detection-using-tcs3200230-a1e463
  digitalWrite(s1,HIGH);
 
 servo.attach(SERVO_PIN);
  servo.write(70);
 
 
 //Wire.begin();
  delay(2000);
 
  // int connection;
  // do {
  //   connection = mpu.setup(0x68);
  //   Serial.println("Not connected");
  // } while(!connection);
}
// 30 limite derecha
// 130 limite izquierda
void loop() {

  if (stringComplete) {
    inputString.trim(); // To eliminate spaces or line jumps
      degs = inputString.toInt();
      servo.write(degs);
    
    inputString = "";
    stringComplete = false;

  }
  /*
  if (stringComplete) {
    inputString.trim(); // To eliminate spaces or line jumps
 
    //get ultrasonics data
    if (inputString.equalsIgnoreCase("ul")) {
      Serial.println(ul.Distance());
    }
    else if (inputString.equalsIgnoreCase("ur")) {
      Serial.println(ur.Distance());
    }
   
    //get color data
    else if (inputString.equalsIgnoreCase("c")) {
      // The combination of s2 and s3 configure the sensor to be sensitive to a certain kind of light (and so a color), LOW LOW for red, LOW HIGH for green
      // and HIGH HIGH for blue
      digitalWrite(s2,LOW);        
      digitalWrite(s3,LOW);       
      GetColorData();
      Serial.print("-");
     
      digitalWrite(s2,LOW);
      digitalWrite(s3,HIGH);
      GetColorData();
      Serial.print("-");
     
      digitalWrite(s2,HIGH);
      digitalWrite(s3,HIGH);
      GetColorData();
     
      Serial.println();
    }
 
    //get yaw
    else if (inputString.equalsIgnoreCase("y")) {
      Serial.println(yaw, 2);
    }
 
    //set servo angle
    else {

    }
 
    // limpiar para la próxima lectura
    inputString = "";
    stringComplete = false;
   
    // if (mpu.update()) {
    //     static uint32_t prev_ms = millis();
    //     if (millis() > prev_ms + 25) {
    //         yaw = mpu.getYaw();
    //         prev_ms = millis();
    //     }
    // }
  }
*/
// Lectura de ultrasonidos
distance_usl = ul.Distance();
distance_usr = ur.Distance();

// Lectura de colores
digitalWrite(s2, LOW);
digitalWrite(s3, LOW);
int r = pulseIn(out, LOW);

digitalWrite(s2, LOW);
digitalWrite(s3, HIGH);
int g = pulseIn(out, LOW);

digitalWrite(s2, HIGH);
digitalWrite(s3, HIGH);
int b = pulseIn(out, LOW);

// Enviar TODO junto una sola vez
Serial.println(String(distance_usl) + "|" + String(distance_usr) + "|" + String(r) + "|" + String(g) + "|" + String(b));

  delay(59);
}


// This function executes automatically when data comes from serial
void serialEvent() {
  while (Serial.available()) {
    char inChar = (char)Serial.read();
    if (inChar == '\n') {  // fin de línea
      stringComplete = true;
    } else {
      inputString += inChar;
    }
  }
}

void PrintColorData(){
   data=pulseIn(out,LOW);  //We begin timing when out goes LOW and stop when it returns to HIGH, the lower the time, the higher the color wave frequency
   Serial.print(data);
   delay(20);
}

long getStableDistance(SR04 sensor) {
  long d1 = sensor.Distance();
  delay(20);
  long d2 = sensor.Distance();
  delay(20);
  long d3 = sensor.Distance();
  
  // Ordenamos para tomar la MEDIANA (mejor que promedio si hay valores locos)
  long arr[3] = {d1, d2, d3};
  for(int i=0;i<3;i++){
    for(int j=i+1;j<3;j++){
      if(arr[j] < arr[i]){
        long temp = arr[i];
        arr[i] = arr[j];
        arr[j] = temp;
      }
    }
  }
  return arr[1]; // valor del medio = mediana
}

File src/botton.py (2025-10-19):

from robot_hat import Pin
import time
import os

button = Pin("SW", Pin.IN, Pin.PULL_UP)   # Botón USR (GPIO25)
led = Pin(26, Pin.OUT)                    # LED (GPIO26)

# Ruta del archivo que quieres ejecutar
script_path = "/home/admin/Documents/pruebaAbierta1.py"

while True:
    if button.value() == 1:  # Presionado
       led.on()
        os.system(f"python3 {script_path}")  # Ejecuta el otro script
        time.sleep(0.5)  # Evita que se repita por rebote
    else:
        led.off()
    time.sleep(0.1)

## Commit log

2025-09-30 First sketch of the robot
    [PrototipoRobot.f3d]
2025-10-15 cambiando direccion
    [PrototipoRobot.f3d]
2025-10-15 Update README to reflect current project scope
    Removed outdated video demonstration topics and additional documentation sections from the README.
2025-10-15 Revise components and sensors in README.md
    Updated component specifications and sensor details in the README.
2025-10-19 Resize images in the Second Prototype Design section
    Updated image sizes in the README for better clarity.
2025-10-19 Document chassis modifications and results
    Updated the README to reflect chassis modifications and their impact on vehicle dimensions and functionality.
2025-10-19 Revise battery mounting system details in README
    Updated the battery mounting system section with an image placeholder and improved description.
2025-10-19 Update README to remove battery holder image
    Removed image placeholder for battery holder section.
